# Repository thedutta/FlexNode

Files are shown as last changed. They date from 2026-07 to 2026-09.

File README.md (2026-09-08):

# FlexNode

**A distributed compute node for mobile robots — high-current FOC actuation and sensor fusion, all over CAN-FD.**

> ⚠️ **Work in progress — first article booted 2026-09-06, first motor spin under FOC 2026-09-08.** A v1.0 board powers up, boots from flash, runs the FlexNode firmware, and has driven a GIM 8108-8 open-loop from its own power stage (DRV8353S, all three phase-current channels, bus-voltage sense and FET thermals validated). Still unvalidated: closed-loop FOC and calibration (encoder not yet fitted), the phase-order fix on hardware, CAN enumeration, ToF and aux current sense. Expect breaking changes until the first article is fully proven.

---

## The vision

Building a legged robot today means building three projects: the robot, its electronics, and the firmware to glue them together. FlexNode's goal is to delete the last two.

**Buy FlexNodes + actuators + sensors. Wire power and CAN. Done — no electronics development.**

Each FlexNode is one node per joint: it closes a hard-real-time field-oriented control loop locally (15–30 kHz), reads its own IMU and time-of-flight sensor, and exposes ports for whatever the joint needs — an external RC servo, an AS5600L joint encoder, a load cell for foot contact, addressable status LEDs. Everything reports and commands over a single daisy-chained CAN-FD pair. One firmware image serves every node; per-node behavior is *configuration*, not code. A host — a Jetson, a laptop, a Raspberry Pi — composes queries per node and gets exactly the telemetry it asks for, at gait-loop rates.

The result: a 21-DoF sensor-fused quadruped's entire electronics stack is ten identical boards (one per BLDC actuator; twelve were ordered for attrition), two wires between them, and a config file. That is sweet for CATBOT (the robot this was built for), and just as sweet for anyone else building anything with motors and sensors on it.

## What it is

FlexNode is a compact 4-layer PCB that fuses a **field-oriented motor controller** and a **sensor-fusion front end** into a single CAN-FD bus node. It began as a fork of the [mjbots **moteus r4.11**](https://github.com/mjbots/moteus) controller — the proven power stage, gate driver, STM32G4 core, FOC firmware, and register protocol are kept intact — and adds the digital sensing and I/O a distributed robot node needs:

- **6-axis IMU** (accel + gyro) for per-node inertial sensing — ten nodes make a distributed IMU array
- **Multizone time-of-flight** ranging (8×8) for proximity / terrain
- **Servo / Aux port** with onboard 5 V current sensing (stall detection)
- **Dedicated I²C port** for AS5600L-class joint encoders or any I²C peripheral
- **SPI pads** with spare GPIOs as chip-selects for SPI peripherals
- **Addressable RGB status** (WS2812)
- Everything on the **moteus CAN-FD register protocol**, extended with a FlexNode register block (`0x080–0x0FF`) — one universal map, per-node-composed queries, host-side fleet autodiscovery

## Core specs (v1.0)

| Domain | Part / value |
|---|---|
| MCU | STM32G473CEU6 / G474CEU6 — Cortex-M4F @170 MHz, 512 KB flash, 128 KB RAM, 5× ADC, 6× op-amp, 3× FDCAN, UFQFPN48 |
| Gate driver | TI DRV8353S (3-phase, SPI-configurable) |
| Power FETs | BSC016N06NS-class — 60 V, 1.6 mΩ, TDSON-8 |
| Motor supply | Up to ~44 V bus (10S LiPo class) |
| Aux rail | LGS5160C sync buck (→ 5 V @ 3 A) + ME6216A33M3G LDO (→ 3.3 V) |
| Rotor feedback | AS5047P magnetic encoder (SPI, on-axis) |
| Comms | CAN-FD 1M/5M via TCAN334G, daisy-chain in/out, leaf-node 120 Ω termination |
| Protocol | moteus register protocol + FlexNode block `0x080–0x0FF` — see [`docs/can-layer.md`](docs/can-layer.md) |
| IMU | ST LSM6DS3TR-C (I²C) |
| ToF | ST VL53L7CX 8×8 multizone (I²C) |
| Status | WS2812B addressable LED |
| Aux I/O | Servo / LED output + 5 V shunt current sense + I²C port + dual CAN ports, all JST-PH |
| Stackup | 4-layer, 1 oz copper (thermally validated for CATBOT's real phase currents; go 2 oz for full moteus current capability) |

## Firmware

Firmware is a fork of moteus, retaining its FOC inner loop, CAN protocol, and flash/bootloader layout. The compatibility layer is **implemented and building**; full deltas in [`docs/firmware.md`](docs/firmware.md):

- **Board identity is hardcoded** to `{family = 0, hw_version = 8}` (r4.11-class). FlexNode repurposes moteus's hardware-detection strap pins (PB11, PC6, PB10), so the runtime autodetection was **deleted outright** — boot never touches the repurposed pins, and `hw_version = 8` selects the correct DRV8353 register tables and r4.11 analog map for free.
- **Pin remaps**: `PC6 → AS5047 CS` (done) · `PB11 → 5 V current sense`, `PC13 → servo/LED`, `PB10 → ToF INT` (with peripheral bring-up).
- **Phase-order fix (implemented)**: the v1.0 copper swaps the A/C motor PWM outputs relative to moteus (PA0 → INHC, PA2 → INHA) while current-sense wiring stays stock — verified pin-by-pin against both schematics. Unfixed, the current loop would regulate the wrong winding. The fix is a **two-line drive-side pin remap** in the hardware table: the PWM CCR mapping follows the pins generically, so the entire control core stays byte-for-byte stock and calibration/`phase_invert` semantics are preserved.
- **Flash budget (measured)**: application image ≈ 408 KiB of the 446 KiB app window → **~36 KiB free** for FlexNode's additions — ample when reusing moteus's non-blocking I²C / SPI-DMA / FDCAN primitives and never blocking the FOC ISR.

## The distributed CAN layer

Designed and specified in [`docs/can-layer.md`](docs/can-layer.md). The short version:

- **Extend, don't invent**: moteus's register protocol already separates a *fixed register map* from *per-node-composed frames* — so every FlexNode shares one universal register layout (`0x080` capabilities bitmask, load cell, AS5600L, IMU, ToF, NeoPixel, servo blocks) while the host queries each node only for what it actually has.
- **One image, N configs**: node identity (CAN id, pin modes, encoder sources, peripheral enables) is persistent config. The whole fleet flashes the same `.elf`.
- **Two-lane cadence**, strictly poll-response: loop-critical data (foot contact, joint angles) rides the per-cycle command+query frame; everything else refreshes on a rotating ~25 Hz slow lane. Promoting a sensor to the fast lane is a host-side change only.
- **Phased host**: bring-up on an mjbots fdcanusb at 250–350 Hz on one chain; scale to 400 Hz–1 kHz by making CATBOT's core board an STM32G4 "spinal cord" driving two chains (the G4 has three FDCAN peripherals).

## Engineering highlights

Choices worth reading the docs for:

- **Buck inductor sized against the silicon, not the app note**: 10 µH at 400 kHz keeps peak inductor current (~3.55 A at full load) under the LGS5160C's 3.7 A high-side current limit — the smaller "typical" value would have current-limited at a third of the rated output.
- **Every BOM line datasheet-verified**: all 37 JLCPCB part numbers resolved and checked against their LCSC datasheets before fab (which caught stale schematic annotations that would otherwise read as fatal design errors).
- **Deleted, not bypassed, hardware autodetect**: less flash, and boot provably never drives the repurposed strap pins.
- **A two-line phase-topology fix**: re-pairing drive and sense windings via the pin table instead of touching control code — zero risk to the FOC core, verified against both netlists first.
- **On-node contact thresholding**: foot contact is computed on the node and read as a single byte in the fast lane — the cheapest possible loop-rate signal, and the seed of local reflexes later.
- **ToF's 84 KB init blob streamed over CAN at boot** instead of consuming flash the MCU doesn't have — the host feeds it through the moteus diagnostic tunnel.
- **Thermal design against real loads**: 1 oz 4-layer copper validated against CATBOT's actual phase-current profile (~2–5 A nominal, ~25 A stall transients) — the actuators thermally limit before the board does.

## About this project

FlexNode and CATBOT are **independently designed and built by [Aditya Dutta](https://thedutta.github.io)**, a third-year undergraduate at **Manipal Institute of Technology, Bengaluru** — no lab budget, no research group, no sponsor: one student, open-source tools, and JLCPCB.

**CATBOT** is the driving target: a 4.9 kg, 21-DoF, super-agile jumping quadruped — high-torque geared hips, lightweight leg motors, a Jetson for perception and locomotion policies, and one FlexNode per actuator fused into a whole-body sensor network. The ambition is deliberately at the edge of what an individual can build: dynamic, sensor-rich legged locomotion of the kind usually gated behind institutional hardware.

The method makes that possible: **stand on proven open source and extend it honestly.** moteus contributes a decade of motor-control engineering; FlexNode contributes the distributed-sensing node architecture, the CATBOT-specific hardware, and the documentation trail — and gives all of it back under the same license. Every schematic, BOM line, firmware delta, and design decision in this repo is public precisely so the next student can start where this project stands instead of where it started.

## Repository layout

FlexNode's files live at the repo root; the upstream **moteus r4** project this forks from is kept intact underneath, in `moteus-r4-parent/`:

```
<repo root>/                     ← FlexNode
├── README.md                    ← you are here
├── .gitattributes               LF pinning for WSL-executed scripts
├── docs/
│   ├── hardware.md              hardware architecture, pin map, power tree
│   ├── firmware.md              firmware port: deltas, phase fix, build/flash
│   ├── can-layer.md             distributed CAN layer: registers, cadence, bus budget
│   └── roadmap.md               status and next steps
├── hardware/
│   ├── FlexNode_schematics.pdf  v1.0 schematic (as ordered)
│   ├── CAD/                     3D model (STEP)
│   ├── manufacturing/           BOM, gerber archive, pick-and-place
│   └── gerbers/                 unpacked gerbers
├── LICENSE                      Apache-2.0 (inherited from moteus)
├── NOTICE                       attribution to moteus / mjbots, trademark note
└── moteus-r4-parent/            ← the moteus r4.11 fork FlexNode builds on
    ├── fw/ hw/ lib/ tools/ …    moteus firmware + build system
    ├── README.md                moteus's own readme
    └── LICENSE                  moteus's original Apache-2.0 (preserved)
```

> **Firmware lives in `moteus-r4-parent/`** and builds from *inside* that directory — its Bazel `WORKSPACE` is the build root. FlexNode's firmware deltas live in `moteus-r4-parent/fw/` (currently concentrated in `moteus_hw.cc`; see [`docs/firmware.md`](docs/firmware.md)).
>
> **Upstream sync:** moteus is deliberately relocated off the repo root so FlexNode is the top-level project, which means `git merge upstream/main` no longer applies cleanly. To pull upstream moteus fixes, `git fetch upstream` and copy/patch the changes into `moteus-r4-parent/` by hand. That manual sync is the accepted trade for owning the root.

## Status

See [`docs/roadmap.md`](docs/roadmap.md) for the live checklist. In short: **first article assembled and booted (2026-09-06) · power tree, flash boot, status LED and IMU validated · first spin 2026-09-08: power stage, phase-current sense, bus sense and FET thermals validated with open-loop drive · CAN layer designed, not yet implemented · encoder fit, closed-loop FOC, phase-order verification and CAN bring-up next.**

## Credits & license

FlexNode derives from the **mjbots moteus r4.11** open-hardware controller by Josh Pieper ([mjbots/moteus](https://github.com/mjbots/moteus), Apache-2.0). The power stage, gate-driver topology, STM32G4 core, FOC firmware, and CAN register protocol follow that project; the sensing suite, distributed-node architecture, CATBOT-specific hardware, and firmware deltas are FlexNode's.

This repository is licensed **Apache-2.0** (`LICENSE` at the root), inherited from moteus and covering FlexNode's additions unless a specific file states otherwise. Attribution and modification notices required by Apache §4 are collected in `NOTICE`; moteus's original license is preserved in `moteus-r4-parent/LICENSE`. Retain the moteus attribution and the upstream link.

"moteus" and "mjbots" are trademarks of mjbots Robotic Systems LLC. FlexNode is **moteus-compatible** (speaks the moteus register protocol and works with `moteus_tool` and fdcanusb) and is not endorsed by or affiliated with mjbots.

Author: **Aditya Dutta** · Manipal Institute of Technology, Bengaluru · Project: **CATBOT**

## Build notes

Working notes for the firmware and bench (what is validated, the bench rules, how to build/flash/debug, and lessons learned) live in [`notes/`](notes/). Read [`notes/README.md`](notes/README.md) first. Bench tooling is in [`tools/bench/`](tools/bench/).

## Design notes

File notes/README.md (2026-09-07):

# FlexNode build notes

Working notes for the FlexNode firmware and bench, kept so that each new session (human or Claude) starts with what the last one learned instead of re-deriving it. These are practitioner notes, not user docs; the polished story lives in [`../docs/`](../docs/).

**Read first, every session:** [`working-together.md`](working-together.md) (how we operate) and [`bringup-log.md`](bringup-log.md) (what is validated vs still gated).

| File | What it holds |
|---|---|
| [`working-together.md`](working-together.md) | Ground rules: commit identity, safety gates on motor work, the `!` prefix for hardware commands, subagent use |
| [`bench-setup.md`](bench-setup.md) | Physical bench: SWD header, the NRST rule, power, ST-Link driver, what "standalone" means |
| [`build-and-flash.md`](build-and-flash.md) | WSL build, image layout, the flash script and its modes, option bytes, flash budget |
| [`debugging-over-swd.md`](debugging-over-swd.md) | Diagnostic toolkit: PC sampling, reading RAM by symbol, what each openocd error actually means |
| [`ws2812-led.md`](ws2812-led.md) | The status LED: behaviour, why the timing is DWT-only, the "colour that never turns off" trap |
| [`firmware-map.md`](firmware-map.md) | Where things live in the fork, how to add a register / an aux I²C device / a config group |
| [`bringup-log.md`](bringup-log.md) | Chronological record of what was validated when, and the remaining hard gates |
| [`hardware-io.md`](hardware-io.md) | What I/O the board actually has, per-node peripheral assignment, and the trades available |
| [`corenode.md`](corenode.md) | Corenode architecture: two-FDCAN split, its own IMU, the IMU-ODR latency finding, pre-schematic snags |
| [`can-layer-design.md`](can-layer-design.md) | Why the CAN layer is shaped the way it is — decisions and the reasoning behind them |
| [`flash-findings.md`](flash-findings.md) | Where the flash actually went, measured. Overturns an earlier assumption |
| [`open-questions.md`](open-questions.md) | Decisions still pending: CAN adapter, encoder, head-gimbal topology, node count |
| [`../reports/`](../reports/) | Dated standing reports for Aditya; first: [`2026-09-07-firmware-flash-optimisation.md`](../reports/2026-09-07-firmware-flash-optimisation.md) — the flash decision document, written to be read once |

Conventions:
- Dates are absolute (YYYY-MM-DD). "Today" rots.
- **Findings carry a date and time stamp** — `YYYY-MM-DD HH:MM TZ` — at the point the finding is
  recorded. Aditya asked for this on 2026-09-07 so that the order things were learned in stays
  recoverable, and it applies to every future finding, not just the ones already here.
- A `> Gotcha:` callout marks something that already cost real time.
- `<!-- self: ... -->` HTML comments are notes-to-self for Claude; invisible on GitHub, visible in the source.
- When a note stops being true, edit it. Don't append contradictions.

Tooling referenced throughout lives in [`../tools/bench/`](../tools/bench/).

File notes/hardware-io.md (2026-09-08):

# Hardware I/O — what the board actually has

What a FlexNode v1.0 can physically be asked to do, and what it cannot. Written because the CAN
channel model made the limits concrete, and because two of them were nearly designed around
incorrectly. Companion to [`../docs/hardware.md`](../docs/hardware.md) (the polished version) and
[`../docs/can-layer.md`](../docs/can-layer.md) §9.

## Off-board I/O inventory

_Recorded 2026-09-07 01:35 IST, from `fw/moteus_controller.cc:401-500` (family-0 aux tables) and
`fw/moteus_hw.cc` (pin remaps), cross-checked against `docs/hardware.md`._

| Resource | Pins | Peripheral backing | Notes |
|---|---|---|---|
| I²C1 | PB8 / PB9 | `I2C1`, `USART3` alt | aux2. Onboard LSM6DS3TR-C (0x6A) + VL53L7CX (DNP) + J2 external port. 2 kΩ pull-ups |
| Servo / LED out | PC13 | **TIM1_CH1N (AF4), TIM8_CH4N (AF6)** | aux1 pin 0. No *aux-table* timer, but the silicon has two |
| SPI2 pads | PB13 / PB14 / PB15 | `SPI2`, ADC | aux1 pins 1–3. Also ADC-capable |
| 5 V rail sense | PB11 | ADC | 50 mΩ high-side shunt, ~32 mA/LSB |
| ToF INT | PB10 | EXTI | |
| Debug / GPIO | PC14 / PC15 | nothing | aux2 pins 2–3 |
| WS2812 | PF0 | bit-banged, DWT-timed | status LED, see [`ws2812-led.md`](ws2812-led.md) |
| Rotor encoder | PC6 (CS) | **SPI2? see gotcha** | AS5047P, **not yet soldered** |

> Gotcha, 2026-09-07 02:40 IST: **"PC13 has no timer" is false as a hardware claim** — I recorded
> it that way earlier. It has no timer *in the moteus aux table*. The G474 maps `PC_13` to
> **TIM1_CH1N (AF4)** and **TIM8_CH4N (AF6)** (`TARGET_STM32G474xE/.../PeripheralPins.c`), so a
> **hardware-timed servo pulse via TIM8_CH4N** is available — and TIM8_CH4N is the right choice
> over TIM1_CH1N because TIM1 is wanted for the SimpleFOC Mini below. The RTC-domain drive
> caveats (weak ~3 mA, slow slew) still stand. Lesson: an absent entry in a vendor table is not an
> absent capability in the silicon.

> ⚠️ Gotcha, 2026-09-08: **the AS5047 may be on SPI2 = PB13/PB14/PB15, not SPI1.** This file
> previously recorded SPI1. For family 0 the onboard AS5047 appears to ride **SPI2**
> (`moteus_controller.cc:409-411,518-520`, `aux_mbed.h:604-605`, upstream `encoders.md:188-190`).
> If true, the "SPI expansion pads" **are the rotor-encoder bus**, and the plan to drive a
> SimpleFOC Mini from TIM1_CH1N/2N/3N on those same pins collides with the one peripheral the axis
> cannot lose. **This is now the deciding question for the Mini, and it is a netlist check on the
> real board, not a code read.** Trace PB13/14/15 and the AS5047 before any `bldc_ext` work.

> Gotcha, 2026-09-07 01:35 IST: **the aux hardware tables are still stock moteus r4 pinouts.**
> `GetAux1HardwareConfig()` / `GetAux2HardwareConfig()` in `fw/moteus_controller.cc` were never
> updated for FlexNode, because FlexNode reports `hw_family = 0` and inherits the r4 tables.
> Aux2 happens to be right (PB8/PB9 I²C is genuinely where the IMU is, and it is verified working).
> Aux1 is **not** verified against the FlexNode PCB — PC13 matches, PB13/14/15 are plausible given
> the "SPI expansion pads" in `docs/hardware.md`, but nobody has traced them on a real board.
> Do that before designing anything that depends on aux1.

## Per-node peripheral assignment

_From Aditya, 2026-09-07 01:35 IST. This is design intent, not something read off the board._

Every node is "one actuator plus what that joint needs to know about itself", and the assignment
was **spaced deliberately from the beginning** so no node is overloaded:

- **One servo per node, never two.** The 7 DS3235/DS3230 servos hang off 7 *different* FlexNodes.
- **Shoulder nodes (2× GIM 8108-8) each carry a SimpleFOC Mini as well as their main axis.** One of
  the two also has a DS3235; the other has spare capacity for load cell / RGB / whatever.
- Nodes are meant to have a **local id/name**, not just a numeric CAN id — see
  [`can-layer-design.md`](can-layer-design.md).

> Gotcha, 2026-09-07 01:35 IST: I initially recommended a **PCA9685 I²C PWM expander** to solve
> "seven servos, one pulse pin". **That recommendation was wrong and is withdrawn** — it solved a
> problem that does not exist, because the servos were never going to share a node. One pulse on
> PC13 is sufficient *per node* — and per the correction above it can even be hardware-timed via
> TIM8_CH4N. The lesson is to ask how the mechanical layout distributes load before optimising a
> per-node resource.

## The trades available

Aditya, 2026-09-07 01:35 IST: *"pc13 is definitely not alone, the i2c pins can be repurposed as
gpio if the lsm6dtr is not used — didnt think that one out i think desoldering it works though.
i2c fallback gpio expansion is always an option."*

So the per-node resource picture is a **trade**, not a fixed budget:

| Keep | Give up | Gain |
|---|---|---|
| IMU + ToF + I²C encoders + I²C ADC on PB8/PB9 | PB8/PB9 as GPIO | the whole I²C peripheral ecosystem on 2 wires |
| PB8/PB9 as plain GPIO (desolder the LSM6DS3TR-C) | IMU, ToF, all I²C peripherals | 2 free GPIOs |
| I²C **plus** an expander (PCA9685 / MCP23017) | nothing | many PWM or GPIO channels on the existing 2 wires |

The expander option is the interesting one and stays on the table for *future* nodes that need
more channels than v1.0 breaks out — it just isn't needed for the servos.

Practical consequence for the channel model: a node's populated channel list is genuinely
per-node, and two nodes with identical silicon can differ by a desoldering operation. That is
exactly why capabilities are discovered at runtime (register 0x080 / channel `type`) rather than
assumed from a part number.

## What is still genuinely blocked

**The SimpleFOC Mini.** A Mini (DRV8313-class) needs 3 PWM + enable. PC13 cannot supply that, and
the shoulder nodes need it *simultaneously with* their own GIM 8108-8 on the main axis — so this
is not an either/or with the onboard FOC, it is an addition to it.

Candidate path: **PB13/PB14/PB15 → TIM1_CH1N (AF6) / CH2N (AF6) / CH3N (AF4)**, confirmed in
`TARGET_STM32G474xE/.../PeripheralPins.c`. Three hardware PWM channels from one timer is exactly
what a Mini wants.

> Gotcha, 2026-09-07 02:40 IST: **motor PWM is on TIM5, not TIM2.** I recorded TIM2 earlier and it
> was wrong. `moteus_hw.h` defaults `pwm1/2/3 = PA_0_ALT0 / PA_1_ALT0 / PA_2_ALT0`; on the G474
> map `PA_x_ALT0` is **TIM5_CHx (AF2)** — plain `PA_x` would have been TIM2 (AF1). TIM5 is also the
> CAN bootloader's time base. The conclusion (TIM1 is free) survives; the reasoning did not.

**Timer allocation, audited 2026-09-07 02:40 IST.** Claimed: **TIM5** (motor PWM + bootloader),
**TIM15** (mbed `us_ticker` + `MillisecondTimer`), **LPTIM1** (ADC trigger, `bldc_servo.cc:685`);
TIM2/TIM3 only if aux1 hardware quadrature is configured; TIM4 only in non-FlexNode families.
**Free: TIM1, TIM8, TIM16, TIM17, TIM20.**

Four constraints on the TIM1 path, none fatal, all easy to trip over:
- **`PB_14` is in FlexNode's aux1 pin table** (slot 1, ADC ch5) — must be `kNC` or aux and the Mini
  fight over it.
- **CHxN-only drive needs `CCxNE`/`CCxNP` + `MOE`** — complementary outputs are not enabled by the
  ordinary channel-enable path.
- **TIM1 BRK shares a vector with TIM15** (`TIM1_BRK_TIM15_IRQn`), which mbed uses. Don't enable
  TIM1 break interrupts.
- **A shoulder node with both a Mini and a DS3235 cannot put the servo on TIM1_CH1N/PC13** — same
  channel as PB13. Use **TIM8_CH4N** for the servo.

Costs:
- the SPI expansion pads (SPI peripherals and an external BLDC become mutually exclusive);
- a **second commutation path in firmware** — open-loop or lightly closed against an I²C
  AS5600/MT6701, not a second FOC stack. Budgeted **~10–13 kB**, which now fits easily. **Write it
  separate; share nothing with `bldc_servo`.**
- **CPU**, on a core already running a 30 kHz FOC ISR. **Headroom unmeasured** — no ISR cycle
  instrumentation exists. Only metric: `system_info.idle_rate` (`system_info.cc:75`), readable over
  SWD as a delta of `moteus::SystemInfo::idle_count`.

> Gotcha, 2026-09-07 02:40 IST: **the CORDIC is a single shared peripheral**, used inside the FOC
> ISR with a write→read sequence. A main-loop user gets pre-empted mid-transaction and reads
> someone else's result. A Mini commutation path must use **software sin/cos or a LUT — never the
> shared CORDIC.** Failure mode would be rare unreproducible torque glitches on *both* axes, which
> is close to the worst thing to debug on this machine.

Firmware-side availability confirmed 2026-09-07 02:40 IST; **pad breakout on the real board is not** — trace it. Three options and their trade-offs are written up
in [`../docs/can-layer.md`](../docs/can-layer.md) §9.2. Nothing should be committed to a v1.1
board revision until TIM1 availability and the PB13/14/15 breakout are confirmed on real hardware.

## Possible bench unblock: moteus_tool over serial, no CAN adapter

_Found 2026-09-07 03:05 IST while auditing removable drivers — the driver that looked most cuttable
turned out to be the most useful thing on the bench._

moteus has a **`kSerial` aux UART mode** (`aux_common.h:104`, "fdcanusb ASCII protocol for serial
control") backed by a `UartFdcanusbMicroServer` (`aux_port.h:443,1404`). It speaks the **full
multiplex register protocol over a plain 3.3 V UART** — same protocol as CAN, same registers, same
`moteus_tool`.

On family 0, **USART3 is on PB_8 / PB_9** (`fw/moteus_controller.cc:462-463`) — exactly the pins
broken out on FlexNode's **J2 I2C port**. So a ~$2 USB-TTL adapter on J2 plausibly gives
`moteus_tool` access **without an fdcanusb**.

Unblocks most of what is gated on "no CAN adapter":
- enumerate the node, read 0x080 (capabilities) and 0x0FF (block version)
- read bus_V vs a DMM — **the R30 rescale has never been verified**
- write 0x0B1 = 255 and watch the LED go red (pixel regs are on PF0, independent of this bus)
- exercise `conf set` / `conf write` and the persistent-config page for the first time

> Gotcha: **the IMU and ToF live on that same bus.** Serial mode and I2C are mutually exclusive —
> while the port is a UART the IMU is unavailable. Fine for the list above; don't expect both.

Check before relying on it:
- **PB8 is also BOOT0.** nSWBOOT0 is already cleared so boot-from-flash is safe, but the pin is
  doing triple duty (BOOT0 / I2C / UART) — verify idle levels.
- **The site's connector list mentions a TX/RX header that docs/hardware.md does not.** If one
  exists in copper, find which pins — family-0 aux1 has no USART, so it would be PB8/PB9 anyway.
  Netlist question for Aditya.

> Gotcha: `kSerial` / `UartFdcanusbMicroServer` (5,917 B) was on the flash cut list. **Do not cut
> it** — it may be the only way to talk to a FlexNode until a CAN adapter exists. A neat
> illustration of why "unused driver" is a claim to verify, not assume.

## I²C bus loading

Everything shares one bus: IMU + ToF + every I²C encoder + a load-cell ADC + any expander. At
400 kHz an AS5600 angle read is ~150 µs and an IMU burst ~300 µs, so a node polling both at 1 kHz
spends ~45 % of the bus. Two cheap mitigations:

- The 2 kΩ pull-ups are **already sized for Fast-mode Plus (1 MHz)**, which cuts all of the above
  by ~2.5×. Verify with a scope on the first assembled node.
- Poll rates need not match the control rate. An RC servo's outer loop at 200 Hz is plenty, and
  the IMU is configured for 104 Hz anyway.

Part choice matters here: prefer **NAU7802** (I²C, 24-bit) for load cells over HX711 (2-wire
bit-bang, needs two GPIOs) and ADS1220 (SPI, contends with the pads above).

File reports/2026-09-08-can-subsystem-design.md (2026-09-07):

# CATBOT CAN subsystem — design

_2026-09-08. Supersedes the fleet assumptions in [`docs/can-layer.md`](../docs/can-layer.md) (13 nodes, Jetson-or-brainstem master) with Aditya's corrected inputs of 2026-09-08: **10 FlexNodes, every one with its own BLDC axis, varying effectors, one corenode as bus master, Jetson behind the corenode, ~45 cm bus.** Builds on [`reports/2026-09-07-can-layer.md`](2026-09-07-can-layer.md). Where this document contradicts `docs/can-layer.md`, §12 lists the spec change._

> **Nothing here has been tested. There is no CAN adapter on the bench.** Every byte count is derived from the moteus source in this repo (file:line cited); every microsecond is arithmetic from the CAN FD frame format and the TCAN334G datasheet; every "recommended" value is untested. The three quantities that most need measuring before this is trusted are marked **[measure]**.

---

## 0. Bitrate is not loop rate — read this first

Aditya: *"I do not understand what Hz has to do with anything, I thought CAN-FD maxes out at 5 Mbps, so Hz is the clock speed of CAN?"*

There are two different numbers, and they live at different layers.

**Bitrate** is a property of the wire. CAN FD sends each frame in two phases: the *arbitration phase* at **1 Mbit/s** (one bit every 1 µs — slow, because every node must see every bit before the next starts so that two nodes starting together can resolve who wins), and the *data phase* at **5 Mbit/s** (one bit every 200 ns — fast, because by then exactly one node is transmitting). Both numbers are fixed by the transceiver (TCAN334G is a 5 Mbit part), the controller configuration (`fw/moteus.cc:213-214`: `slow_bitrate = 1000000; fast_bitrate = 5000000`) and the ISO standard. They say how long *one frame* takes on the wire. They say nothing about how often you send one.

**Loop rate in Hz** is a schedule the master chooses. One "cycle" means: the corenode sends every node its command and gets every node's reply. The loop rate is how many such cycles happen per second. It is bounded by the bitrate — you cannot complete a cycle faster than the sum of all its frames — but it is not the same thing, any more than a road's speed limit is the same as how many buses a day you run on it.

The derivation, end to end, with real numbers (details in §3 and §5):

| Step | Quantity | Value |
|---|---|---|
| 1 | Time for one 16-byte command frame on the wire (48 arbitration-rate bits at 1 Mbit + 161 data-rate bits at 5 Mbit) | **80 µs** |
| 2 | Time for the node's 12-byte reply | **74 µs** |
| 3 | Per-node round trip (command + reply), plain actuator node | **154 µs** |
| 4 | Ten nodes, using the actual mix in §5 (two heavy, six medium, two plain) | **1,704 µs** |
| 5 | Plus one slow-lane request+reply pair per cycle (§5.3) | **+246 µs → 1,950 µs per cycle** |
| 6 | Maximum loop rate if the bus were 100 % busy: 1 / 1.95 ms | **513 Hz** |
| 7 | Keep the bus ≤ 65–70 % busy (retransmissions, error frames, node turnaround jitter, bit stuffing): 513 × 0.65…0.70 | **330–360 Hz usable** |

So: **5 Mbit/s is the wire; ~350 Hz is the schedule; the bus is then about two-thirds occupied.** The coordinator's rough figures (≈190 µs per node, ≈1.9 ms per cycle, ≈515 Hz ceiling, 300–400 Hz usable) check out: per node it is 154–194 µs on the fast lane plus a 25 µs share of the slow lane, the cycle is 1.95 ms, the ceiling 513 Hz, and the usable band 300–385 Hz depending on how much margin you keep.

Two rates that are *not* the loop rate, for orientation: the FOC current loop inside each FlexNode runs at 30 kHz and never touches the bus; the Jetson's policy runs at whatever rate it runs and the corenode interpolates between its outputs at bus rate.

---

## 1. Topology

```
 Jetson Orin Nano Super ──(USB / UART / SPI — undecided, §11)── corenode (STM32G4, FDCAN1)
                                                                    │ J3
                                                          FlexNode 1 ── 2 ── 3 ── … ── 10
                                                          (120 Ω)                    (120 Ω)
```

- **One master.** The corenode owns every frame on the bus. FlexNodes transmit only in reply to a frame addressed to them (the single exception, if it is ever built, is §9).
- **10 nodes, ids 1–10**, daisy-chained J3-in/J4-out per [`docs/hardware.md`](../docs/hardware.md), terminated at the corenode end and at node 10 only.
- **Jetson behind the corenode.** The Jetson never appears on the CAN bus. The corenode is the only node that can be a G1 beacon source (§9) and the only thing that can enumerate the fleet.
- **Growth path:** a second chain on the corenode's FDCAN2 (the STM32G4 has three FDCAN instances). Not needed at 10 nodes (§6).

The corenode must therefore have FDCAN. **An STM32G0 cannot be the corenode** — it has no FDCAN peripheral. This settles the G0/G4 question raised in `open-questions.md` §8 as far as the bus master goes; whether a separate G0 exists for the zero-watt acoustic-wake duty is a power-architecture question, not a bus one.

---

## 2. Physical layer

### 2.1 Propagation over 45 cm: not a constraint

Signal velocity in twisted pair is ≈ 0.2 m/ns (≈ 5 ns/m). End to end over 45 cm: **≈ 2.3 ns one way, ≈ 4.5 ns round trip.**

- Against the **1 µs arbitration bit**: the CAN arbitration rule is that a dominant bit from the far end plus the transceiver loop delay must arrive before the local sample point. Round trip is 2 × (2.3 ns + 135 ns loop) ≈ 275 ns against a sample point at 671–800 ns (§2.4). **Margin ≈ 400–500 ns.** Length is 0.5 % of the budget; the transceiver is the rest.
- Against the **200 ns data bit**: only one node transmits, so propagation does not limit anything except the transmitter checking its own bit (§2.5).
- **Where length would start to matter.** Arbitration at 1 Mbit fails when 2 × (5 ns/m × L + 135 ns) exceeds roughly 600 ns, i.e. **L ≈ 30–40 m** — the textbook "40 m at 1 Mbit". At 5 Mbit the limit is not propagation but ringing: the TCAN334G differential edge is ≈ 17 ns (datasheet t_r), and a line is electrically "lumped" — reflections are invisible — while its round trip is well under the edge time. At 5 ns/m that is roughly **< 1 m total**, with stubs under ≈ 30 cm. CATBOT's 45 cm bus is comfortably inside. Past ~1–2 m of total wire, or stubs past ~30 cm, the data phase would start to need CiA 601-style stub discipline. *(Rule-of-thumb figures; the ISO/CiA guidance is not in this repo.)*

### 2.2 Star vs daisy-chain at 45 cm

**Would a star work?** Electrically, at this length, yes. A hub with ten ≤ 20 cm stubs has stub round trips of ≈ 2 ns, an order of magnitude under the 17 ns edge, so each stub's reflection is over before the driver has finished the edge. Total capacitive load — ten transceivers at ~20 pF plus ~1.5 m of wire at ~50 pF/m — is ≈ 300 pF, and the TCAN334G is characterised at 100 pF (60 Ω) and 200 pF (120 Ω). The star would sit somewhere between those two datasheet columns: functional, with the "highly loaded" loop-delay figure (180 ns max) becoming the relevant one — which matters for §2.5.

**Daisy-chain is still the right call, for reasons that are not convention:**

1. **The hardware already does it.** J3-in/J4-out is on every board; a star needs a hub board with ten connectors and twenty crimps that does not exist.
2. **Termination is unambiguous.** Two physical ends, two 120 Ω bridges. A star has no "ends" — you terminate the two longest branches and hope, which is exactly the kind of thing that works on the bench and fails at 40 °C.
3. **Wire mass and routing.** A chain along a limb is one pair going out and one coming back at each joint; a star is ten pairs converging on the torso.
4. **Lower total capacitance**, keeping the transceiver in its 100 pF column.

The one real cost of a chain: a break in the pair at joint *k* kills nodes *k+1…10* and leaves nodes *1…k* single-terminated. At 45 cm single-termination still works (§2.3), so the upstream half degrades rather than dies. That is the fault-containment argument for two chains later.

### 2.3 Termination: what actually goes wrong

Nominal: 120 Ω at each physical end, 60 Ω in parallel as seen by any driver.

- **A middle node also terminated (three resistors, 40 Ω).** The driver must source ~50 % more current to reach the same differential voltage. The TCAN334G guarantees ≥ 1.5 V dominant differential into 60 Ω; into 40 Ω the amplitude drops toward the 0.9 V receiver threshold and the margin against noise and ground offset shrinks. It usually still "works" on a short quiet bench bus and fails first in the field. Every node terminated (12 Ω) and the driver cannot reach dominant at all — the bus is dead.
- **Only one end terminated (120 Ω).** Dominant amplitude is fine (higher, in fact). The problem is the *recessive* edge: nothing drives recessive; the terminators pull the pair back together through the bus capacitance. Doubling R doubles that time constant. The datasheet's "highly loaded" column (120 Ω, 200 pF) is exactly this case, and it lists loop delay up to **180 ns** and 5 Mbit received-bit symmetry down to 120 ns — against a 200 ns bit. At 1 Mbit you will not notice. At 5 Mbit, bit-symmetry and the transmitter's own loopback check (§2.5) start failing intermittently. Diagnosable: it works with `bitrate_switch` off and fails with it on.
- **Neither end.** Reflections from open ends; at 45 cm they settle in nanoseconds, so it may even work — right up to the first cable that is a bit longer. Do not.

### 2.4 Bit timing on the STM32G4 FDCAN

FDCAN kernel clock is PCLK1 = **85 MHz** (the firmware's own comment: `tdc_offset = 13; // 13 / 85MHz ~= 152ns`, `fw/moteus.cc:226`). `MakeTime()` (`fw/fdcan.cc:44-72`) picks prescaler 1 and splits the remaining time quanta ≈ 3 : 1 between seg1 and seg2. What the FlexNode firmware therefore programs today:

| Phase | tq per bit | Prescaler | Seg1 | Seg2 | SJW | Sample point |
|---|---|---|---|---|---|---|
| Nominal, 1 Mbit | 85 | 1 | 56 | 28 | 16 | (1+56)/85 = **67 %** |
| Data, 5 Mbit | 17 | 1 | 11 | 5 | 5 | (1+11)/17 = **71 %** |

Both sample points are earlier than usual practice (CiA recommends ≈ 80 % nominal, 75–80 % data; the STM32 examples use 80 %/75 %). Earlier sampling is more tolerant of ringing and less tolerant of propagation and loop delay. On a 45 cm bus ringing is a non-issue and loop delay is the whole budget, so **later is better here**:

| Phase | Recommend | Sample point | Why |
|---|---|---|---|
| Nominal | prescaler 1, seg1 = 67, seg2 = 17, SJW = 17 | 68/85 = **80 %** | Standard; maximises the arbitration loop-delay budget. |
| Data | prescaler 1, seg1 = 12, seg2 = 4, SJW = 4 | 13/17 = **76.5 %** | Pushes the loopback check 12 ns later (§2.5); SJW 4 tq (47 ns) still covers oscillator tolerance between HSI-clocked nodes. |

Both are within the G4 limits `MakeTime` enforces (255/127 nominal, 31/15 data). The mechanism to apply them without touching `MakeTime` already exists — `ApplyRateOverride` (`fw/fdcan.cc:74-89`) — but the `Rate` override struct is not currently exposed as `can.*` config; that is a small firmware addition. **Every node and the corenode must use identical settings.** Clock source caveat: FlexNode has no HSE crystal (`docs/hardware.md`), so the 85 MHz derives from HSI16 at ±1 % over temperature; SJW ≥ 4 tq in the data phase is what absorbs that. **[measure]** with an adapter: error counters at 5 Mbit over a warm-up.

### 2.5 Transceiver reality check: TDC

At 5 Mbit the transmitting controller compares each bit it sends against what it reads back through its own transceiver, at the data sample point. If the transceiver's loop delay exceeds the sample-point position, it reads the *previous* bit and raises a bit error. Transmitter Delay Compensation (TDC) moves that check later by a measured/configured offset.

| | Value | Source |
|---|---|---|
| Data sample point, firmware today | 12 tq / 85 MHz = **141 ns** after bit start | §2.4 |
| TCAN334G loop delay, 60 Ω / 100 pF | 100 ns typ, **135 ns max** | datasheet SLLSEQ7F §5.6 `tPROP(LOOP)` |
| TCAN334G loop delay, 120 Ω / 200 pF | 120 ns typ, **180 ns max** | same |
| MCU pin + controller internal delays | ~10–20 ns | estimate |
| TDC in FlexNode firmware | **disabled** for family 0 | `fw/moteus.cc:224`: `delay_compensation = g_measured_hw_family != 0` |

The moteus comment says family 0 "uses a TCAN334GDCNT, which has a very low loop delay". The datasheet says the margin at the firmware's sample point is **141 − 135 = 6 ns** worst case in a well-terminated bus, and **negative** in a heavily loaded or single-terminated one. Thousands of moteus r4.x boards run 5 Mbit this way, so typical parts clearly clear it — but the design should not rely on typicals.

**Recommendation:** enable TDC for FlexNode — `options.delay_compensation = true`, keep `tdc_offset = 13` (153 ns ≈ seg1 with the §2.4 timing, per ST's guidance of offset ≈ DataTimeSeg1 × prescaler) and `tdc_filter = 2`. It costs nothing, the code path exists and is exercised by other moteus families, and it converts a 6 ns margin into ~150 ns. Two-line change in `fw/moteus.cc`. **[measure]**: with TDC on and off, error counters over 10⁶ frames.

Nothing else about the TCAN334G constrains the design: 5 Mbit is its rated maximum, 45 cm is nothing, and the 100 pF column is where a two-terminator chain of ten sits.

---

## 3. Frame anatomy and cost

### 3.1 Frame time model

CAN FD frame bits, from ISO 11898-1:2015 field lengths:

- **Arbitration rate (1 Mbit):** 11-bit id: SOF 1 + ID 11 + RRS 1 + IDE 1 + FDF 1 + res 1 + BRS 1 = 17 bits up front, plus ACK 1 + ACK-delim 1 + EOF 7 + IFS 3 = 12 bits at the tail → **29 µs**. 29-bit id adds SRR 1 + ID-ext 18 → 36 up front → **48 µs**.
- **Data rate (5 Mbit):** ESI 1 + DLC 4 + 8·N data + CRC field + CRC-delim 1. CRC-17 (N ≤ 16 bytes) with its stuff-count and fixed stuff bits is 27 bits; CRC-21 (N > 16) is 32. So **8N + 33 bits for N ≤ 16, 8N + 38 for N > 16**, at 200 ns each.
- Dynamic bit stuffing in the data adds 0–20 % of the data-phase bits depending on content; it is absorbed in the utilisation margin, not modelled per frame.

**Every command frame is a 29-bit frame**: the host sets bit 15 of the id to request a reply (`lib/python/moteus/transport.py:344`) and the firmware sends any id ≥ 2048 as extended (`fw/fdcan.cc:323-325`). A **reply** has id `(node << 8) | 0`, which is < 2048 for node ids 1–7 (11-bit frame, 19 µs cheaper) and ≥ 2048 for ids 8+. Payloads are rounded up to the next legal DLC — 12, 16, 20, 24, 32, 48, 64 — by `RoundUpDlc` (`fw/fdcan.cc:24-41`).

| Payload (DLC) | 29-bit frame | 11-bit frame |
|---|---|---|
| 8 | 67 µs | 48 µs |
| 12 | 74 µs | 55 µs |
| 16 | 80 µs | 61 µs |
| 20 | 88 µs | 69 µs |
| 24 | 94 µs | 75 µs |
| 32 | 107 µs | 88 µs |
| 48 | 132 µs | 113 µs |
| 64 | 158 µs | 139 µs |

The DLC steps are the whole game for frame design: **33–48 bytes all cost 132 µs; 25–32 all cost 107 µs.** Every frame below is designed to land just under a boundary, and the table says where.

### 3.2 Subframe encoding (stock moteus, `lib/cpp/mjbots/moteus/moteus_multiplex.h`)

Header byte = `0x00` write / `0x10` read / `0x20` reply, `| type<<2` (int8 0, int16 1, int32 2, float 3), `| count` if count ≤ 3, else count 0 and a following count byte (`:646-652`). Then the start register as a varuint (1 byte ≤ `0x7F`, 2 bytes to `0x3FFF`), then the values. Consecutive registers, one subframe.

### 3.3 Arbitration priority — a quirk to know and not rely on

Base id of every corenode command is 0 (bits 28–18 of `0x8000|dest` are zero). Replies from nodes 1–7 are 11-bit frames with base id `node << 8` ≥ 0x100, so **a corenode command always beats them**; replies from nodes 8–10 are extended with base id 0 and a smaller 18-bit extension than the command, so **they beat the corenode**. Consequence: if the corenode streamed ten commands back-to-back, nodes 1–7 could not get a reply in until it paused. The schedule in §5.4 sends with at most two commands outstanding, which sidesteps this entirely. Do not build anything that depends on reply priority.

---

## 4. Node classes and their frames

Aditya: every node has a BLDC axis; some add a servo; some add a servo and a SimpleFOC Mini; some have "other effectors". Four classes cover that; a node's class is whatever its enumerated channel list says (`docs/can-layer.md` §8), not a build-time choice.

Design rules applied to all of them (each a spec change, §12):

- **Fast pair.** Each channel's per-cycle command is `cmd_a, cmd_b` (2 × int16 at `+4`) and its per-cycle readback is `meas_a, meas_b` (2 × int16 at `+7`). `cmd_c` (effort limit) and `meas_c/d` go on the slow lane. Two registers keep the count in the header's low bits — no count byte — so a channel command is 7 B and a readback request 3 B / reply 7 B.
- **Axis fast query is `0x000–0x003` only.** Voltage, temperature and fault (`0x00D–0x00F`) move to the slow lane. Mode (`0x000`) is read every cycle and equals 1 on fault, so fault *detection* latency is unchanged; only the fault *code* waits ≤ 29 ms for the slow lane. This saves 2 B in every command and 5 B in every reply — which is what keeps class C under DLC 32.
- **Mode is written every cycle** (`01 00 0A`). It is 3 bytes, it re-arms the axis, and it is what the stock Python library does; not worth optimising away.

### 4.1 Class A — actuator only

**Command → DLC 16** (14 B, 2 B spare)

| Bytes | Subframe | B |
|---|---|---|
| `01 00 0A` | write int8 ×1 @ `0x000` mode = 10 (position) | 3 |
| `07 20 pp pp vv vv tt tt` | write int16 ×3 @ `0x020` position, velocity, ff-torque | 8 |
| `14 04 00` | read int16 ×4 @ `0x000` mode, position, velocity, torque | 3 |

**Reply → DLC 12** (11 B, 1 B spare)

| Bytes | Subframe | B |
|---|---|---|
| `24 04 00` + 8 | mode, position, velocity, torque | 11 |

Round trip: 80 + 74 = **154 µs** (135 µs if the node id is ≤ 7).

### 4.2 Class B — actuator + one servo (slot 1 = `servo_rc`)

**Command → DLC 24** (21 B, 3 B spare)

| Bytes | Subframe | B |
|---|---|---|
| (class A command) | | 14 |
| `06 94 04 aa aa ss ss` | write int16 ×2 @ `0x214` servo angle, slew | 7 |

No servo readback on the fast lane: a DS3235 has no feedback unless an `enc_i2c` is bound, and its 5 V current (stall detection) is a 35 Hz question. **Reply → DLC 12**, as class A. Round trip **168 µs** (149 µs, id ≤ 7).

Designed under the boundary: 14 + 7 = 21 ≤ 24. Adding a 3-register servo command (with `cmd_c`) would make 23 — still 24. Adding the 3-byte servo readback request would make 24 — still 24, but the reply would go 11 + 7 = 18 → DLC 20 (+14 µs). If a servo *does* have a bound encoder and its angle matters at gait rate, that is the price.

### 4.3 Class C — actuator + servo + SimpleFOC Mini (slot 1 `servo_rc`, slot 2 `bldc_ext`)

**Command → DLC 32** (31 B, 1 B spare — this is the tightest frame in the fleet)

| Bytes | Subframe | B |
|---|---|---|
| (class A command) | | 14 |
| `06 94 04 aa aa ss ss` | servo angle, slew @ `0x214` | 7 |
| `06 A4 04 pp pp vv vv` | write int16 ×2 @ `0x224` Mini position, velocity | 7 |
| `16 A7 04` | read int16 ×2 @ `0x227` Mini position, velocity | 3 |

**Reply → DLC 20** (18 B)

| Bytes | Subframe | B |
|---|---|---|
| `24 04 00` + 8 | axis | 11 |
| `26 A7 04` + 4 | Mini position, velocity | 7 |

Round trip 107 + 88 = **195 µs** (176 µs, id ≤ 7).

This is where the two design rules pay: with the spec's original 3-register commands and 4-register readbacks and `0x00D–0x00F` on the fast lane, this command would be 47 B → DLC 48 (132 µs) and the reply 27 B → DLC 32 (107 µs): **239 µs**, 44 µs more per cycle per shoulder. One more byte in the command as designed and it also jumps to 48 — so **class C has no room for a third effector on the fast lane.** A third effector goes on the slow lane or costs 26 µs.

### 4.4 Class D — actuator + one fast input (foot load cell, or output-side encoder)

Command = class A + `16 97 04` (3 B) = 17 → **DLC 20**. Reply = 11 + 7 = 18 → **DLC 20**. Round trip **176 µs** (157 µs, id ≤ 7). Which nodes, if any, carry a foot load cell is not stated anywhere; class D is here so the budget can absorb it.

---

## 5. The schedule

### 5.1 What rotates and what does not

Aditya asked for round-robin keyed off node id so nothing starves. The answer is that **the fast lane is not a rotation at all: every node is served every cycle, in id order 1→10.** Starvation is impossible by construction. What rotates is the **slow lane**: on cycle *c*, node `(c mod 10) + 1` additionally receives a slow-lane request. Keying it off the id means the schedule is a counter and a modulo, which is exactly right for a purpose-built fleet.

At 350 Hz that is **35 slow-lane visits per second per node**. Whether that is a 35 Hz refresh of *everything* depends on whether a node's slow block fits one 64-byte reply (§5.3).

### 5.2 Fast lane composition, per cycle

Assumed fleet — the counts are Aditya's qualitative statement turned into numbers and are **assumed, not stated**: 2 class C (the two shoulder nodes: GIM 8108-8 + Mini, one with the DS3235), 6 class B (six more servos, one per node, on six actuator nodes — that uses all seven published servos), 2 class A. If "other effectors" add fast channels, they move a node to class D at +22 µs each.

| Class | Count | Cmd / reply DLC | Round trip (id ≥ 8 / id ≤ 7) | Subtotal (all extended) |
|---|---|---|---|---|
| C | 2 | 32 / 20 | 195 / 176 µs | 390 µs |
| B | 6 | 24 / 12 | 168 / 149 µs | 1,008 µs |
| A | 2 | 16 / 12 | 154 / 135 µs | 308 µs |
| **Fast lane** | 10 | | | **1,706 µs** |

Give ids 1–7 to the seven busiest nodes and the fast lane drops to ≈ 1,573 µs. The budget below uses the conservative all-extended figure.

### 5.3 Slow lane

One request+reply pair per cycle, to the rotating node. Content, in one 64-byte reply where it fits:

| Subframe (request) | Reply bytes | What |
|---|---|---|
| `13 0D` | 5 | voltage, temperature, fault |
| `14 08 80 01` (int16 ×8 @ `0x080`) | 20 | caps, status, rail current, profile, build hash, channel count, fleet role, host-loss state |
| `14 06 98 01` (int16 ×6 @ `0x098`) | 16 | IMU accel + gyro (v1 alias) |
| per channel: `16 92 04` (+2..+3) and `17 99 04` (+9..+B) | 8 + 10 | status, mode; `meas_c`, `meas_d`, nonce |

Class A/B/D: 5 + 20 + 16 + 18 = **59 B → DLC 64** ✓ (35 Hz for the whole block). Class C: two channels = 77 B — does not fit. **For class C the slow lane alternates**: even visits carry health + IMU, odd visits carry both channel blocks; each half refreshes at **17.5 Hz**. That is still above the 25 Hz the spec called "ample" for IMU bias tracking only on A/B nodes; for the two shoulders it is below it. If the shoulder IMUs turn out to feed state estimation, promote their IMU read to the fast lane on those two nodes (+4 B request, +16 B reply → command DLC 48 on a class C node: +26 µs each; budgeted in §6 as "next thing that breaks").

Slow request ≈ 20 B → DLC 20 (88 µs); reply DLC 64 (158 µs). **Slow pair = 246 µs per cycle.** Slow-lane *writes* — `cmd_c` effort limits, `0x023–0x029` gains and limits, servo re-arm — ride in the same request frame; they cost reply bytes only if they ask for a reply (they should not).

### 5.4 Cycle timeline at 350 Hz (period 2,857 µs)

The corenode keeps **at most two commands in flight** (send command *k+1* as soon as command *k* has left the TX FIFO, but never command *k+2* until reply *k* has arrived or a 300 µs per-node timeout has expired). This hides node turnaround behind the next command's transmission, guarantees the bus is free for a reply after every second command regardless of the priority quirk in §3.3, and bounds the damage from a dead node to one timeout per cycle.

```
 t (µs)   bus
    0     ┌─ cmd 1 (C, 107) ─┐┌─ cmd 2 (C, 107) ─┐┌ reply 1 (88) ┐┌─ cmd 3 (B, 94) ─┐┌ reply 2 (88)┐
  ~480    ┌─ cmd 4 (B) ─┐┌ reply 3 (74) ┐┌─ cmd 5 (B) ─┐┌ reply 4 ┐┌─ cmd 6 (B) ─┐┌ reply 5 ┐ …
 ~1540    … ┌─ cmd 10 (A, 80) ─┐┌ reply 9 ┐┌ reply 10 (74) ┐
 ~1710    ┌─ slow req → node (c mod 10)+1 (88) ─┐┌──────── slow reply, DLC 64 (158) ────────┐
 ~1950    ┌ FaF pixel (67) ┐┌ FaF servo-arm (67) ┐  … up to a cap of 3 frames / 250 µs
 ~2200    ·········· idle slack ≈ 650 µs (retransmits, error frames, stuffing, turnaround jitter) ··········
 2857     next cycle
```

Where each thing lands:

- **Fast lane, 0 → ~1,710 µs.** Commands in id order; replies interleave. Reply *k* arrives after node *k*'s turnaround, which is main-loop latency (`fw/moteus.cc:348-353` polls CAN RX from the `for(;;)` loop) — **[measure]**, unmeasured, probably tens of µs, hidden by the two-in-flight rule as long as it is under one frame time.
- **Slow lane, ~1,710 → ~1,960 µs.** One pair.
- **Fire-and-forget, ~1,960 → ~2,200 µs.** Pixel colour, tare, servo re-arm, named-posture broadcast: drained from a queue with a per-cycle cap (3 frames or 250 µs) so they can never push the next cycle. Fire-and-forget frames have no reply bit, so they are 11-bit frames (48 + data) — cheap.
- **Slack, ~2,200 → 2,857 µs.** ≈ 23 % of the period. This is where automatic retransmission (`fw/moteus.cc:217`, on) and error frames go without stealing from the next cycle.

The corenode's own FDCAN has, on the G4, a fixed message RAM of **3 TX FIFO elements and 3 + 3 RX FIFO elements** (RM0440; not re-verified in this repo). Ten replies arrive ~75–110 µs apart; the corenode must service RX from an interrupt, not a main loop, or the fourth reply overwrites the first. Note it in the corenode firmware requirements.

### 5.5 Operating points

Cycle cost 1,952 µs (all-extended, assumed mix). Utilisation = cost × rate.

| Loop rate | Period | Bus utilisation | Slack per cycle | Verdict |
|---|---|---|---|---|
| 200 Hz | 5,000 µs | 39 % | 3,048 µs | Bring-up. Room for verbose slow lane, tunnel traffic, debugging. |
| 250 Hz | 4,000 µs | 49 % | 2,048 µs | Comfortable. |
| 300 Hz | 3,333 µs | 59 % | 1,381 µs | **First walking target.** Under the 65 % rule with margin for class-D additions. |
| **350 Hz** | 2,857 µs | **68 %** | 905 µs | **Design operating point.** Just over the 65 % rule; acceptable because the slack is still 4–5 frames wide. |
| 400 Hz | 2,500 µs | 78 % | 548 µs | Ceiling for a single chain. One retransmit storm eats the slack. |
| 450 Hz | 2,222 µs | 88 % | 270 µs | Not viable — slow lane and fire-and-forget starve. |
| 500 Hz | 2,000 µs | 98 % | 48 µs | Not viable. |

With ids 1–7 on the busiest nodes (1,819 µs): 350 Hz → 64 %, 400 Hz → 73 %.

**Recommended: 1 Mbit / 5 Mbit (unchanged), 350 Hz loop, ≈ 68 % utilisation, ≈ 0.9 ms slack.** Bring up at 200 Hz, walk at 300 Hz, tune toward 350 Hz. Nothing in the servo (50–330 Hz devices) or policy path benefits from more, and the FOC loop is local at 30 kHz regardless.

---

## 6. What breaks first, and the upgrade path

In the order it will happen:

1. **A class C node grows one byte.** 31 → 32 is fine; 33 is DLC 48 and +26 µs. Adding a fast IMU read to a shoulder, a third effector, or per-cycle stiffness (§7.2) does it. Two shoulders → +52 µs/cycle → 350 Hz goes from 68 % to 70 %. Survivable once; not twice.
2. **Fast input channels spread.** Each node promoted to class D is +22 µs. Four foot load cells → +88 µs → 71 %.
3. **Node count.** Each added class A node is +154 µs; a class B, +168 µs. At 12 nodes the 350 Hz point is ≈ 80 %. At 13 (the old assumption) it is ≈ 86 % — which is why the old spec's 325 Hz / 65 % line was already optimistic.
4. **Slow-lane refresh** on class C is already at 17.5 Hz per half; a fourth channel on a node pushes it to three-way alternation.
5. **Corenode RX servicing** (§5.4) — a software problem, not a bus one, but it will look like a bus one.

**Upgrade path: second chain on FDCAN2.** Split 5/5 by side (or front/rear). Each chain's cycle is ≈ 0.95 ms; at 350 Hz that is ≈ 33 %, and 600 Hz becomes reachable at ≈ 57 %. Termination: each chain gets its own two ends (corenode end + last node). The corenode runs two identical schedulers offset by half a period so its RX interrupt load is even. The FlexNodes need nothing — `can.prefix` can namespace the two chains if they are ever bridged, but physically separate buses do not need it. This is also the fault-containment split the site already promises ("one bus fault takes down one side"). Not needed at 10 nodes; the design is written so that enabling it is a corenode change only.

---

## 7. Command and telemetry semantics

### 7.1 Who computes what

- **Jetson** runs the policy. Its output should be **per-joint targets** — position, velocity and feed-forward torque for each of the ten axes, plus servo angles and Mini positions — at policy rate. Whether the policy emits joint space directly or foot coordinates that something converts through IK is a Jetson/corenode software decision and is **not stated**; the bus does not care, but the corenode must receive joint-space targets at least as often as it wants to change them, and it interpolates (or holds) between policy updates at bus rate.
- **Corenode** owns the schedule, packs frames from templates (§7.4), unpacks replies into a fleet-state struct, hands the Jetson a consolidated state at whatever rate the Jetson wants, and runs the failure policy (§9) without the Jetson.
- **FlexNode** runs FOC at 30 kHz on the axis, the servo pulse and the Mini commutation locally, and answers what it is asked.

### 7.2 Registers, by lane

| Lane | Direction | Registers | Notes |
|---|---|---|---|
| Fast, every cycle | cmd | `0x000` mode = 10; `0x020` position, `0x021` velocity, `0x022` ff-torque | stock (`fw/moteus_controller.cc:236,270-272`) |
| Fast | cmd | `0x2n4` `cmd_a`, `0x2n5` `cmd_b` per channel | servo: angle, slew · Mini: position, velocity |
| Fast | tel | `0x000–0x003` mode, position, velocity, torque | mode = 1 flags a fault immediately |
| Fast | tel | `0x2n7` `meas_a`, `0x2n8` `meas_b` for Mini (and class-D inputs) | Mini: position, velocity · load cell: force, **contact** · encoder: angle, rate |
| Slow, 35 Hz (17.5 Hz on C) | cmd | `0x023` kp scale, `0x024` kd scale, `0x025` max torque, `0x028` velocity limit, `0x029` accel limit; `0x2n6` `cmd_c` effort limits; `0x2n3` channel mode | stock `0x023–0x02A` (`:273-280`). Written only when changed. |
| Slow | tel | `0x00D–0x00F`; `0x080–0x087`; `0x098–0x09D` IMU; per channel `+2,+3,+9,+A,+B` | see §5.3 |
| Fire-and-forget | cmd | `0x0B0–0x0B4` pixel; tare; servo re-arm; named posture (broadcast `0x7f`) | no reply bit, 11-bit frames |
| Boot only | both | `0x100`, `0x150–0x153`, `0x0FF`, `0x0C0–0x0C3` name, channel `type/caps` | `docs/can-layer.md` §8 |

**Per-cycle stiffness modulation** (`0x023–0x025` every cycle, as some policies want) costs +8 B in every command: class A 22 → DLC 24 (+14 µs), class B 29 → DLC 32 (+13 µs), **class C 39 → DLC 48 (+26 µs)**. Fleet cost ≈ +150 µs/cycle → 350 Hz at 73 %. Affordable on a single chain only if nothing else grows; free on two chains. Decide when the policy exists.

### 7.3 Servo semantics on the wire

`servo_rc` `cmd_a` is the target angle in 0.05° (int16), `cmd_b` the slew limit in 0.5 °/s (resolution table in `docs/can-layer.md` §3.5). The node runs the pulse train and slew limiting; if an `enc_i2c` is bound it closes the outer loop locally. The corenode writes the target every cycle whether or not it changed — that is the servo channel's watchdog refresh (§9). `cmd_c` (5 V current limit for stall cut-off) is slow-lane, once.

### 7.4 Frame templates — how the corenode composes a multi-effector frame

At enumeration the corenode builds, per node, a **byte template**: the fixed subframe headers with the value slots left blank, plus a table of (offset, source-field, scale). Per cycle, packing is a `memcpy` of the template and int16 stores at fixed offsets; no varuint encoding or subframe logic runs in the loop. For the class C node in §4.3 the template is 31 bytes with value slots at offsets 2 (mode), 5–10 (axis), 17–20 (servo), 24–27 (Mini). Unpacking uses the same idea in reverse against the expected reply layout; a reply whose subframe headers do not match the template is a protocol error, logged with the node's name (`0x0C0–0x0C3`) and dropped. Templates change only when the channel list changes — i.e. never at runtime, which is the whole point of "hardware changes need a reflash".

---

## 8. Node identity in this topology

Unchanged from `docs/can-layer.md` §4.1: CAN id (1–10, address), UUID (`0x150–0x153`), name (`0x0C0–0x0C3`). The corenode holds the fleet manifest — ten rows of (id, UUID, name, expected class, expected profile/build hash) — and refuses to start the schedule on any mismatch. Give **ids 1–7 to the two class C and five of the class B nodes** (cheapest replies), 8–10 to the rest. Numbering by id in physical chain order is tidy but not required.

---

## 9. Failure policy with the corenode as the only master

`docs/can-layer.md` §7 was written for a Jetson-or-brainstem master. With the corenode as the sole master three things change: the beacon source is fixed, the fast lane *is* a heartbeat, and the question G2 answers becomes "what if the corenode dies" — a different, rarer, event.

### 9.1 What a FlexNode does when corenode frames stop

**Detection.** Stock: `servo.default_timeout_s` (`fw/bldc_servo_structs.h:612`, default **0.1 s**) is reset by every command frame. At 350 Hz a frame arrives every 2.9 ms, so 100 ms is 35 consecutive missed cycles. **Recommend 30 ms** (≈ 10 cycles): long enough that a retransmit burst or a single dropped reply never trips it, short enough that a fallen corenode is noticed within a stride. Config, not code; can be tuned per node. **[measure]** false-trip rate at 30 ms once the bus is real.

**Axis safe state.** On timeout the axis enters `timeout_mode` (`:622`, default **12 = kZeroVelocity**): a velocity-zero servo loop — it does not hold position, it *damps* motion, with torque capped at `timeout_max_torque_Nm` (`:613`, default **5 Nm**). For a 4.8 kg quadruped that is the right primitive: the robot sags to the ground against damping rather than collapsing or locking. Recommend: hips/shoulders (backdrivable QDD) keep mode 12 with the cap tuned to roughly body-weight support so the sag is slow; knees (14:1 belt, less backdrivable) the same, and evaluate mode 15 (brake) only if the belt turns out to overrun.

**Channel safe state**, per type — new firmware, since channels do not exist yet:

| Type | On timeout | Why |
|---|---|---|
| `servo_rc` | hold last target for `ch.hold_ms` (recommend 200 ms), then `mode = 0` (pulse stops, servo goes limp) | An instantly limp spine/tail drops the torso; a stale target held forever fights the sagging legs. A short hold then release is the compromise. |
| `bldc_ext` (Mini) | `mode = 0` immediately: driver disabled, coast | Open-loop commutation with a stale target is worse than coasting. |
| inputs (`loadcell`, `enc_i2c`, `imu`, `tof`) | keep sampling | Nothing to make safe; data is wanted when the corenode returns. |
| `pixel` | fault pattern on pixel 0 | Human-visible "I have lost my master". |

Recovery is automatic: the next valid command frame re-arms the axis (mode write) and the corenode re-arms channels (`mode = 1`) on its first slow-lane visit.

### 9.2 What the corenode does when a FlexNode stops replying

A node that misses its 300 µs reply window is marked stale for that cycle; three consecutive misses mark it *lost*. The corenode keeps commanding it (the frame costs the same either way and re-arms it the instant it is back), tells the Jetson which limb is degraded, and applies the corenode-level fallback: a **standing posture on the remaining nine** with the affected limb's neighbours commanded to hold. This is the "brainstem still has authority to put the robot into a safe pose" from the site, made concrete. It needs no bus feature at all.

### 9.3 G0 / G1 / G2, reconciled

- **G0 — per-node timeout.** As above. Always on. Now with a 30 ms recommendation and per-channel safe states.
- **G1 — presence beacon.** The corenode is the only possible source. But **the corenode already sends every node a frame every 2.9 ms; the fast lane is the beacon.** A separate 10 Hz broadcast adds nothing for liveness. What survives of G1 is the *fleet-state* half: a fire-and-forget broadcast write to `0x086` (`0x7f` destination, already accepted by every node — `fw/moteus.cc:307,319`) carrying a named posture or a "degrade" flag, so the corenode can put all ten nodes into a posture with one frame when the *Jetson* dies. That is the case G1 should be redefined around: **G1 = corenode-driven degraded mode on Jetson loss**, not node-side beacon tracking. Register `0x087` (host-loss state) stays, driven by the node's own G0 timer.
- **G2 — deputy.** With one master, G2 protects against *corenode* death. **Recommendation: do not build it for CATBOT.** The corenode is a G4 running fixed-rate code with a hardware watchdog and no OS — the "boringly predictable" tier by design; its failure is orders of magnitude rarer than the Jetson's, and when it happens G0 already lands the robot in a damped sag within 30 ms, which is a defensible outcome for a 4.8 kg machine. Against that, G2 adds the only unsolicited transmitter on the bus, a fold sequence executed blind by a node that cannot see its peers, and the failure modes listed in the previous report (a wrong deputy is indistinguishable from the host). The one thing worth taking from G2 is a **corenode hardware watchdog that, on reset, immediately broadcasts a "hold" posture** — which is G1's fleet-state frame, sent by the recovering master. Keep §7's G2 text in the spec as a documented, disabled option for a future multi-master fleet; delete `deputy_rank` from the CATBOT config.

### 9.4 Jetson loss

Not a bus event. The corenode notices its Jetson link is silent (its own watchdog, threshold a Jetson-side question — a few hundred ms), stops interpolating toward stale targets, and drives the fleet to a standing or crouched posture from its own table via the fast lane it is already running. The bus schedule does not change at all. This is the failure that will actually happen, and it is handled entirely above the CAN layer.

---

## 10. Bring-up order for this design

Each step is testable with the adapter and no motor.

1. **Adapter.** Everything below is blind.
2. One node: `moteus_tool --info`, read `0x0FF`, `0x080`, name; measure **node turnaround** (command → reply, scope on CANH). **[measure]** — the number that decides whether §5.4's two-in-flight rule hides it.
3. Error counters at 5 Mbit, TDC off vs on (§2.5); adopt the §2.4 sample points via a `can.*` override.
4. Two nodes, ids 1 and 8: confirm the 11-bit/29-bit reply split and the arbitration behaviour of §3.3 on a scope.
5. Class A schedule at 200 Hz from the adapter host: measure real cycle time against 1.95 ms; fit the stuffing overhead.
6. Channel infrastructure (`docs/can-layer.md` §11 steps 4–7) → class B and C frames; confirm DLC 24 / 32 on the wire.
7. G0 at 30 ms: pull the adapter mid-schedule, scope the time to mode 12.
8. Corenode firmware: templates, two-in-flight, RX in interrupt, slow-lane rotation, fire-and-forget cap.
9. Ten nodes at 300 Hz; then 350 Hz; read utilisation from the corenode's own busy-time counter.

Hard gates unchanged: AS5047 soldered before any position work; phase order validated on a current-limited supply before calibration or sustained drive.

---

## 11. Open questions and what each blocks

| Question | Blocks | Level |
|---|---|---|
| **Node turnaround latency** (main-loop polled) | Whether two-in-flight hides it; if > ~100 µs the cycle grows by up to 10 × the excess | **[measure]** |
| **SimpleFOC Mini attachment** (own node / TIM1 on SPI2 pads / v1.1) — unchanged from the previous report | Class C exists at all | Design |
| **Jetson ↔ corenode link** (USB, UART, SPI?) and its rate | §7.1 interpolation; Jetson-loss detection threshold | Design |
| Which nodes carry foot load cells / output encoders | Class D count; +22 µs each | Implementation |
| Does the policy need per-cycle stiffness (`0x023–0x025`)? | +150 µs/cycle; class C → DLC 48 | Implementation |
| Exact effector mix per node (which six actuator nodes host the six non-shoulder servos) | Nothing on the protocol; the manifest | Implementation |
| Whether a separate G0 exists for acoustic wake | Power architecture only; the corenode must be FDCAN-capable regardless | Design (not bus) |

---

## 12. Changes this design requires in `docs/can-layer.md`

For the coordinator to apply; I have not edited `docs/`.

| § | Change |
|---|---|
| 0, scope note | Fleet is **10 nodes**, all with axis 0. Delete the "10 + 3 non-actuator" assumption; `aux` and `sense` profiles are not used on CATBOT. |
| 1, L0 | State that command frames are 29-bit (reply bit) and replies are 11-bit for ids ≤ 7. Add the §3.3 priority note. |
| 3.3 | Define the **fast pair**: per-cycle command = `cmd_a, cmd_b`; per-cycle readback = `meas_a, meas_b`; `cmd_c`, `meas_c/d` are slow-lane. |
| 3.4 | Re-bind so the fast pair is the loop-critical pair: `servo_rc` `meas_b` = 5 V current; `loadcell` `meas_b` = **contact flag**, `meas_d` = force rate. |
| 5.1 | Fast axis query is `0x000–0x003` only; `0x00D–0x00F` moves to the slow lane. Slow lane alternates two blocks on nodes whose block exceeds 64 B. Add the fire-and-forget per-cycle cap and the two-in-flight rule. |
| 5.2 | Replace the frame model with §3.1 (29-bit arbitration cost, CRC-17/21 split, DLC quantisation) and the table in §3.1. |
| 5.3 | Replace the budget table with §5.5; operating point 350 Hz / 68 % on one chain of 10. |
| 6 | Profiles are off the CATBOT path; `full` is the CATBOT image. |
| 7 | G1 = corenode-driven degraded mode on Jetson loss, fleet-state broadcast only; G2 documented but **not built**; add per-channel timeout behaviours and the 30 ms `default_timeout_s` recommendation. |
| 9 (new 9.5) | Physical layer: §2 of this document — sample points, **enable TDC for family 0**, termination rules, chain-not-star rationale. |
| 11 | Build order per §10; add turnaround measurement as step 2. |
| 12 | Close "10 vs 13"; close "brainstem G0 or G4" as "the corenode must be FDCAN-capable"; add the Jetson-link and turnaround questions. |

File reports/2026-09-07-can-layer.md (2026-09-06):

# FlexNode CAN layer — standing report

_2026-09-07. Explains and pressure-tests the v2 design in [`docs/can-layer.md`](../docs/can-layer.md); reasoning in [`notes/can-layer-design.md`](../notes/can-layer-design.md); board limits in [`notes/hardware-io.md`](../notes/hardware-io.md); flash in [`docs/flash-budget.md`](../docs/flash-budget.md). CATBOT facts are from the public site (`/projects/catbot/`, `/projects/flexnode/`)._

> **Nothing in this report, or in the spec it describes, has been exercised on a real CAN bus.** There is no adapter on the bench. Every byte count below is derived from the moteus source in this repo; every microsecond is arithmetic, not measurement.

## 1. What the layer is for, and the two rules

FlexNode makes a *node* — "one actuator plus whatever that joint needs to know about itself" — the unit CATBOT is composed from, and the same board a sellable product. The CAN layer turns thirteen boards into one machine, and it is the product's public API. Two rules follow and decide everything else:

1. **The register map is a stable, versioned, public interface.** A host written against block v2 works against every v2 node, forever. Registers are deprecated, never recycled; `0x0FF` is the version.
2. **What a node *is* may vary; what a register *means* may not.** Nodes differ in populated hardware and compiled features, never in semantics — and unpopulated, unconfigured and uncompiled are deliberately indistinguishable (all answer `kUnknownRegister`).

The layer is an addition, not a replacement: CAN-FD framing and the multiplex subframe protocol stay bit-for-bit stock moteus, which keeps `moteus_tool`, `tview`, the CAN bootloader and the Python library working. FlexNode lives in unused register space — the v1 node block at `0x080–0x0FF` and the new channel slots at `0x200+`.

## 2. The channel model, and why it beats v1

v1 assigned fixed registers per peripheral kind. That works for one robot and fails for a product: every new peripheral type or combination needs a new register range *and* a new host special case.

v2 inverts it. A node exposes up to eight **typed channel slots** at `0x200 + 0x10·slot` (slots 1–8 = `0x210–0x28F`). Every slot has the same 16-register frame: `type, caps, status, mode` at `+0..+3`, commands `cmd_a/b/c` at `+4..+6`, measurements `meas_a/b/c/d` at `+7..+A`, a `nonce` at `+B`, four type-specific. The host discovers each slot's `type` at boot and drives every channel through one driver. A new peripheral is a new enum value, not a new register range.

**The stride is the point.** Subframes address *consecutive* registers, so a full command is one write subframe and a full readback one read subframe. Here is the wire cost for a node with a BLDC axis, a load cell in slot 1 and an I²C encoder in slot 2, both on the fast lane. Subframe headers pack a count of 1–3 into the low two bits; a count of 4 costs a byte (`moteus_multiplex.h:646`). Registers above `0x7F` are two-byte varuints (`0x217` → `97 04`).

**Command frame, host → node 5, reply requested.** CAN id `0x8005`.

| # | Bytes | Meaning | Size |
|---|---|---|---|
| 1 | `01 00 0A` | write int8 ×1 @ `0x000`: mode = position | 3 |
| 2 | `07 20 pp pp vv vv tt tt` | write int16 ×3 @ `0x020`: position, velocity, ff-torque | 8 |
| 3 | `14 04 00` | read int16 ×4 @ `0x000`: mode, position, velocity, torque | 3 |
| 4 | `13 0D` | read int8 ×3 @ `0x00D`: voltage, temperature, fault | 2 |
| 5 | `14 04 97 04` | read int16 ×4 @ `0x217`: load-cell `meas_a..d` | 4 |
| 6 | `14 04 A7 04` | read int16 ×4 @ `0x227`: encoder `meas_a..d` | 4 |
| | | **Total → DLC 24** | **24** |

**Reply frame, node 5 → host.** CAN id `0x0500`.

| # | Bytes | Meaning | Size |
|---|---|---|---|
| 1 | `24 04 00` + 8 | mode, position, velocity, torque | 11 |
| 2 | `23 0D` + 3 | voltage, temperature, fault | 5 |
| 3 | `24 04 97 04` + 8 | force, d/dt, raw counts, **contact flag** | 12 |
| 4 | `24 04 A7 04` + 8 | angle, rate, —, magnet AGC | 12 |
| | | **Total 40 → DLC 48** (8 B padding on the wire) | **40** |

Three things the example teaches that the spec's prose does not:

- **Input-only channels have no command subframe.** The spec's "axis + 2 fast channels = 32 B / 32 B" assumed symmetric command+readback. A sensor channel costs 4 B in the request and 12 B in the reply.
- **DLC quantisation bites.** CAN-FD payloads step 24 → 32 → 48 → 64 (`fw/fdcan.cc:24`). The 40-byte reply goes out as 48; 33 to 48 bytes cost the same.
- **A four-register read is the wrong shape for the fast lane.** If the load cell's *contact flag* were `meas_b` (force-rate moved to `meas_d`), the fast read is two registers: `16 97 04` request, `26 97 04` + 4 reply — 7 B, not 12. Both channels reordered: command 22 → DLC 24, reply 30 → **DLC 32**. One DLC step per node per cycle, for a table edit. The design note's "do not reorder without redoing the bus budget" cuts both ways — this reorder *earns* the redo.

## 3. Cadence, lanes, and the bus budget

Two lanes, one master, strictly poll-response. **Fast lane:** every cycle, one command+query frame per node — stock axis command and query plus each fast channel. **Slow lane:** one node per cycle additionally dumps its full channel set and health; at 13 nodes and 325 Hz that is a 25 Hz refresh per node. Fire-and-forget writes (pixels, tare) fill idle. Promotion from slow to fast is a host schedule change; firmware is untouched.

The spec models a frame as ≈30 µs of arbitration-rate fields plus `(8N+43)` bits at 5 Mbit. **Two corrections are needed before the table is trusted.** `RoundUpDlc` quantises payloads as above. And the model assumes an 11-bit id, but the host sets `0x8000` on every frame that requests a reply (`lib/python/moteus/transport.py:344`) and the firmware sends any id ≥ 2048 as a 29-bit extended frame (`fw/fdcan.cc:323`) — so every fast-lane command is extended, as is every reply from a node with id ≥ 8. The 18 extra id bits plus SRR/IDE at 1 Mbit add roughly **+20 µs per frame** (stuff bits ignored). Recomputed, worst case, all frames extended, slow-lane pair excluded as the spec did:

| Configuration | Cmd / reply DLC | µs per node | 13 nodes @ 325 Hz | Spec said |
|---|---|---|---|---|
| axis only | 16 / 16 | 166 | **70 %** | 55 % |
| axis + 1 input channel (4-reg read) | 20 / 32 | 198 | **84 %** | 65 % |
| axis + 2 input channels (4-reg reads) | 24 / 48 | 230 | **97 %** | 75 % |
| axis + 2 input channels, 2-reg reads | 24 / 32 | 205 | **87 %** | — |
| 2 chains × 7, axis + 1 channel, 400 Hz | 20 / 32 | 198 | **56 %** | 52 % |
| 2 chains × 7, axis + 2 channels, 1 kHz | 24 / 48 | 230 | **161 %** | 130 % |

The spec's two structural conclusions survive, stronger than stated. **Two fast channels per node is the ceiling on one 13-node chain** — with real frame sizes even *one* on every node breaches the 65 % headroom rule. **1 kHz is unreachable on one chain and on two**; 400 Hz on two chains is the right target, and the RC servos are 50–330 Hz devices regardless. Splitting the chain remains the highest-leverage decision: nearly half the load, and fault containment free. Giving ids 1–7 to the nodes that matter most saves ~20 µs on each of their replies.

**Is the two-lane shape right for CATBOT's actual sensors?** Mostly. On a BLDC node the joint angle is already in the stock query (`0x001`), so the channels that earn a fast slot are foot contact, an output-side encoder where the 14:1 belt separates rotor from joint (the site does not say the knees have one), and the *command* side of servos and the SimpleFOC Mini. That is zero to one fast channel on most nodes and two on the shoulders — the budget worry is two nodes, not thirteen. One refinement: schedule each node at a rate divisor (1, 2, 4 … 13) instead of two fixed lanes. Servo-only nodes at half rate cost nothing in firmware and would pull a 13-node chain back under 65 %.

## 4. Host-loss autonomy: G0, G1, G2

The Jetson is "allowed to crash". Three graded answers, only the first mandatory:

- **G0 — independent timeout, always on.** Stock `servo.default_timeout_s` (0.1 s) drops the axis into timeout mode; channels go to `mode = 0`, which is why released is the boot default. No new protocol, no coordination, no shared failure. This is the floor and it is never disabled.
- **G1 — brainstem presence beacon.** A fire-and-forget broadcast to `0x7f` at ~10 Hz; nodes track beacon age in `0x087` and reduce limits when it goes stale. Under 0.1 % of the bus, no election, no node-to-node traffic. **Requires the brainstem to have FDCAN** — §9.
- **G2 — deputy.** If the beacon *also* dies, the node with the lowest non-zero `deputy_rank` waits `rank × stagger_ms` and broadcasts a canned safe sequence. Any host or brainstem traffic demotes it instantly; its authority expires after `authority_ms`.

**G2 is the most dangerous idea in the design, and it should be said plainly.** A node that can command its peers can do so *while it is wrong* — a stuck beacon-age counter, a duplicated rank, a half-dead node that believes the fleet is silent. Three constraints make it survivable and none may be relaxed for convenience: a whitelist of *reducing* actions only (fold, lower, relax, hold — never walk, never raise a limit); authority that *expires* back to G0; and a rank that defaults to 0 so nothing self-promotes. Two things the spec understates. Because moteus ignores the source field, a deputy's frames are indistinguishable from the host's — so **receivers cannot filter a rogue deputy**; a cheap belt-and-braces is to accept a non-host source only while the receiver's own `0x087` ≥ 2. And a broadcast cannot carry per-joint targets, so "fold" must be a *named posture* each node resolves from its own config — those per-joint angles need validating on the standing robot before G2 is ever enabled. Build G0 now, G1 when the brainstem exists, G2 only once CATBOT stands.

## 5. Node identity

A node carries three things that must not be conflated: a **CAN id** (bus address, `id.id`, 1–126), a **UUID** (immutable silicon serial, `0x150–0x153`), and a **name** (`flexnode.name`, 16 NUL-padded UTF-8 bytes at `0x0C0–0x0C3`). The name is in registers, not only a config string, because the text protocol is slow, unavailable to a minimal host, and absent exactly when the name is most wanted — in a fault dump. Four consecutive int32 registers mirror how moteus publishes its UUID, so a name is one subframe, read once at enumeration. The host should assert id, UUID and name against a fleet manifest at boot, alongside profile id and build hash — one refusal catches both a board swapped between joints and a mixed-image fleet. Add `deputy_rank` uniqueness to the same assertion.

## 6. Mapping onto CATBOT

Published fleet: 4× GIM8108-8 "sagittal hips", 6× 5010 knees (14:1 belt), 2× head gimbals on a SimpleFOC dual driver, 7× DS3235/DS3230 servos "hung off node aux ports" — 19 DoF. Aditya's 2026-09-07 statement puts a GIM 8108-8 *and* a SimpleFOC Mini on each of two **shoulder** nodes. I read the shoulders as two of the four GIM8108 nodes (front hips); if they are additional, the site's count of four is wrong. Whether the shoulder Minis *are* the head gimbal driver or a separate pair is stated nowhere.

| Node | Axis 0 | Channels it would declare | Fast-lane load |
|---|---|---|---|
| `shoulder_fl`, `shoulder_fr` | GIM8108-8 | `bldc_ext` (Mini) + `enc_i2c` (Mini feedback) + `imu` + `pixel` + `rail_5v`; one adds `servo_rc` (DS3235), the other has spare capacity ("load cell / RGB") | 2 command channels: cmd 48 / reply 48 — the two heaviest nodes on the bus |
| `hip_rl`, `hip_rr` | GIM8108-8 | `imu`, `pixel`, `rail_5v`, possibly `loadcell` | 0–1 |
| `knee_*` ×6 | 5010 + belt | `imu`, `pixel`; output-side `enc_i2c` and a foot `loadcell` are *plausible but unstated* — which node the foot wires to is undocumented | 0–1 |
| servo nodes | — | `servo_rc` ×1 (+ optional `enc_i2c` feedback), `imu`, `pixel`, `rail_5v` | 1 |

**The 10-vs-13 discrepancy, again.** Ten BLDC actuators get a FlexNode each; the site says thirteen nodes. If 13 = 10 + 3 aux nodes, only 3 of the 7 servos can have dedicated nodes and the other 4 ride on actuator nodes (one is the shoulder's DS3235; three are unknown). If all 7 servos get dedicated nodes, the fleet is 17, and every budget line above gets roughly 30 % worse. This changes the profile mix and the chain split, not the protocol — but it must be settled before the bus is laid out. (The `aux` profile compiles `servo_rc` ×2 against a one-servo-per-node rule; harmless, but worth aligning.)

## 7. Learnings worth keeping

- **`0x7f` broadcast already works.** `fw/moteus.cc:307` accepts `prefix<<16 | 0x7f` on standard and extended filters. G1 and G2 needed no protocol invention.
- **moteus ignores the frame source field**, so a deputy needs no receiver-side change — and that is exactly why a receiver-side sanity check is worth adding (§4).
- **Profiles solved a problem measurement then dissolved.** They were the release valve for a 16.8 kB flash budget; three drive-path-free changes measured −84 kB and a 48.7 kB hole in the linker map was labelled "currently unused". Profiles survive only as a safety/product choice.
- **The PCA9685 was withdrawn** because it optimised a per-node resource (one pulse pin) before asking how the mechanical layout distributed the load (one servo per node, seven nodes). Ask the layout question first.
- **An absent entry in a vendor table is not an absent capability.** "PC13 has no timer" was true of the moteus aux table, false of the silicon (TIM1_CH1N, TIM8_CH4N). Likewise motor PWM is on TIM5, not TIM2 — the conclusion survived, the reasoning did not.
- **Frame cost is not payload length.** DLC steps and the extended-id bit are each worth on the order of 20 % on a small frame; both were missing from the budget (§3).

## 8. Where I disagree, or would push

- **Fix the budget table before anything is scheduled against it** — DLC rounding, extended ids, asymmetric sensor channels. The conclusions hold; the margins do not exist.
- **Put loop-critical measurements first.** Make `meas_a/meas_b` the two registers the fast lane wants for every type (load cell: force, *contact*), so a fast read is a 3-byte request and 7-byte reply. Cheaper to decide now than after the map is public.
- **Eight slots is exactly v1.0's physical ceiling; the address space should not be.** A shoulder with Mini, its encoder, a servo, load cell, IMU, pixel, rail sense and ToF is eight. Reserve `0x210–0x30F` for 16 slots now (free), implement 8, and decide whether onboard fixtures (`imu`, `pixel`, `rail_5v`) consume slots at all — they have v1 aliases, and they eat three of eight on every node if they do. Define `0x085` as *highest populated slot*, not a count, or enumeration stops at the first gap.
- **The 16-register stride suits control-shaped peripherals, not array-shaped ones.** The `imu` binding row is all dashes because six axes do not fit four `meas` registers; its data lives in the v1 alias. Say so, or a second IMU (the head has one) cannot be a channel.
- **Take profiles off CATBOT's critical path.** Space is solved, `full` fits everything, the site already promises "one firmware · N configs", and one image removes the mixed-fleet hazard §6.4 exists to catch. Keep the mechanism for motor-less retail SKUs later.
- **`notes/open-questions.md` is stale** — §2 still says "PC13 has no timer" and "TIM2", §2b still recommends the PCA9685; both contradicted by `hardware-io.md`. Edit in place, as its header asks.

## 9. Open questions, and what each blocks

| Question | Blocks | Level |
|---|---|---|
| **How does the SimpleFOC Mini attach?** Own CAN node (must be FD, not classic), TIM1 on the SPI2 pads (costs SPI expansion; CHxN + MOE setup; software sin/cos, never the shared CORDIC; PB14 `kNC`), or defer to v1.1 | `bldc_ext`, the shoulder nodes, any v1.1 respin | **Design** |
| **Brainstem: STM32G0 or G4?** G0 has no FDCAN; the site says both | G1 beacon, two-chain topology, whether 400 Hz is reachable at all | **Design** |
| 10 vs 13 (or 17) nodes | Chain split, profile mix, bus budget | Implementation |
| Is the Jetson on the bus, or only behind the brainstem? | Two masters or one; where the G1 beacon originates | Implementation |
| Load-cell ADC part (NAU7802 recommended) and which node the foot wires to | `loadcell` channel, contact thresholding | Implementation |
| Do knees carry an output-side encoder? | `enc_i2c` on knee nodes, fast-lane count | Implementation |
| Tunnel throughput for the 84 kB ToF blob × 13 nodes | ToF bring-up time | Implementation |
| **A CAN adapter** | Every line of this report | Bench |

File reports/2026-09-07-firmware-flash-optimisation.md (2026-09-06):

# Firmware flash optimisation — what to do, and what not to delete

_Standing report for Aditya. Measured 2026-09-07 01:20–02:40 IST against the `bee0685` image
(app 437,808 B, 16,848 B free). Full numbers and per-object tables live in
[`docs/flash-budget.md`](../docs/flash-budget.md); this report is the decision document._

## The short version

You do not have to remove a single driver to solve the flash problem.

Three build-level changes, none of which touches the motor drive path and none of which deletes
any functionality, were measured by real builds of an untouched copy of the tree:

| Change | Measured saving | What it deletes |
|---|---|---|
| Link against newlib-nano (the small C library) | −33,916 B | nothing |
| Stop the C++ exception runtime from being linked | −12,316 B (less on top of nano) | nothing |
| Compile one non-realtime file for size instead of speed | −50,144 B | nothing |
| **All three together** | **−84,028 B → 353,780 B image, 100,876 B free** | **nothing** |

That is six times the space you have today, before touching a line of moteus's driver code.
There is a further ~47 kB of physically unused flash between the vector table and the bootloader
that a linker-script change can reclaim, also without deleting anything.

Driver removal is an optional, last-resort lever. Everything measurable in that category adds up
to **19,242 B** — less than a quarter of what the build-level changes give — and it is the only
lever that makes future merges from upstream moteus harder. My recommendation, agreeing with the
coordinator: **keep every driver, take the 84 kB, revisit only if you ever actually run out.**

## What the "removable" drivers actually are

You said: _"I barely understood what drivers are being removed and why … for all we know it does
most of what we're trying to build anyway."_ That instinct is partly right, so here is each
candidate in plain terms. "Could FlexNode use it" means: is there a plausible CATBOT configuration
where this code earns its place.

**iC-PZ (6,637 B).** A driver for the iC-Haus iC-PZ, a high-resolution *optical* absolute encoder
chip that reads a reflective code disc over SPI and has its own calibration register set. It is
used in precision industrial and research actuators. FlexNode's planned encoders are magnetic
(AS5047 onboard, AS5600-class or MT6701 on I²C); an optical disc assembly is not on the roadmap.
This is the one candidate with no plausible CATBOT use. Losing it loses only iC-PZ support. It is
also the cleanest cut technically (its own telemetry channel, no interrupt entanglement).

**BiSS-C (3,832 B plus an unmeasured share of shared code).** Not a chip but a serial *protocol*
used by industrial absolute encoders from Renishaw, RLS, Hengstler and many Chinese servo-encoder
vendors. moteus implements it by bit-banging with a timer and DMA. Nothing in the CATBOT parts
list speaks BiSS-C, and the encoders you are considering (AS5600, MT6701, AS5047) do not. Losing it
loses the ability to bolt an industrial BiSS-C encoder onto an aux port later. Plausible but
unlikely for this robot.

**MA732 (1,040 B).** A driver for the MPS MagAlpha MA732, a cheap, popular SPI magnetic encoder in
the same class as the AS5047. **This one is potentially useful.** If a future joint encoder on the
SPI-capable aux pins ends up being a MagAlpha part — a very normal choice — this 1 kB is exactly
the code you would want. Keep it.

**Quadrature, software and hardware-timer (1,816 B).** Reads incremental A/B (ABZ) pulse trains —
the output mode of classic incremental encoders and also an *alternate output mode* of both the
AS5047 and the MT6701. **Potentially useful**: it is the natural way to give a second axis (for
example the SimpleFOC Mini's motor) a position feed without another SPI bus. Keep it.

**UART "serial" mode — the fdcanusb-over-UART server (5,917 B).** Lets a host computer talk the
same ASCII protocol that the fdcanusb CAN adapter speaks, but over a plain UART on an aux pin. In
other words: `moteus_tool` and tview without a CAN adapter. **You currently have no CAN adapter on
the bench.** If any USART-capable aux pin is reachable on FlexNode (the stock table lists PB3/PB4/
PA15 for USART2 and PB8/PB9 for USART3, the latter being the I²C bus, which becomes free on a node
without the IMU), this driver is a bring-up tool, not dead weight. Keep it, and consider using it.

**The rest — hall, index, sine/cosine, PWM-input, step/dir, AS5048, MA600, AksIM-2, CUI AMT21/22,
Orbis.** These have no standalone code at all any more: the linker's dead-code removal and the
compiler's inlining have already folded them into shared functions, so their individual cost is
*unmeasured and unmeasurable without per-driver experimental builds*. Several are plausibly useful
(hall sensors as a commutation fallback, PWM-input for the PWM mode of AS5600/MT6701, AS5048B as an
I²C encoder sibling of the AS5600, MA600 as MA732's sibling). Treat them as free.

Net: of the five measurable candidates, three (MA732, quadrature, UART serial) are things CATBOT
might genuinely want, one (BiSS-C) is unlikely but harmless, and one (iC-PZ) is dead weight worth
6.6 kB. Your worry was justified.

## Decision table

| Option | Space gained | Capability lost | Merge cost with upstream | Verdict |
|---|---|---|---|---|
| **Keep every driver; apply the three build-level changes** | 84,028 B measured (100,876 B free); +~23–47 kB more from the linker gap | none | none — 2 lines in `fw/BUILD`, one new file, one scoped pragma | **Default. Do this.** |
| Cut the obvious (iC-PZ only) | +6,637 B on top | iC-PZ optical encoders | small, contained edit in `aux_port.h` | Only if you are ever within 7 kB of the wall |
| Cut everything measurable (iC-PZ, BiSS-C, MA732, quadrature, UART serial) | +19,242 B on top | MagAlpha SPI encoders, ABZ incremental input, serial bring-up without CAN, BiSS-C | medium and permanent: exhaustive `switch`es in upstream files, every future merge conflicts | Not recommended |
| Cut the inlined drivers too | unmeasured | hall fallback, PWM-mode encoders, AS5048/MA600 | high; touches the position-sampling interrupt path | Do not |

I agree with the coordinator's read. The only refinement: iC-PZ is a legitimate future cut, but it
buys 6.6 kB against a 100 kB margin, so it is not worth the merge friction today.

## The three build-level changes, in enough detail to apply

**1. newlib-nano.** The firmware currently links the full-size newlib C library because the
`nanospecs` toolchain feature exists in `rules_mbed` but was never enabled for the `moteus`
target. Nano is the same library built for size: its `printf` family, `strtod`, `malloc` and
locale support are a fraction of the full versions. The change is two lines on the `moteus`
target in `fw/BUILD`: add `"nanospecs"` to `features`, and add `linkopts = ["-Wl,-u,_printf_float"]`.

> **Why `-u _printf_float` is mandatory.** Nano's `printf` leaves out floating-point formatting
> unless you explicitly ask for it. moteus prints *every* float — `conf get`, `tel get` in text
> mode, `moteus_tool --dump-config` and `--restore-config`, tview — through `snprintf("%g")`.
> Without the flag the build succeeds, the image is 4,880 B smaller, and every float comes out
> wrong. It is a silent correctness bug, not a build error. (`_scanf_float` is not needed; nothing
> uses `scanf`.)

Verified in the variant build: float printing is present and the C++ exception runtime largely
disappears as a side effect, because nano's C++ library does not drag it in.

**2. The throw-stub file.** Although everything compiles with exceptions disabled, three helper
functions from the standard library (`std::__throw_out_of_range_fmt`, `__throw_length_error`,
`__throw_logic_error`, referenced from `moteus.cc` and two mjlib objects) pull in the whole
exception, RTTI, `std::string` and even `std::random_device` machinery from the prebuilt library.
A new FlexNode-owned file `fw/flexnode_nothrow_stubs.cc` defines those functions (plus the
`optional`/`variant` variants) as `[[noreturn]]` traps. Under `-fno-exceptions` the existing
behaviour on that path is already "terminate", so nothing observable changes. Add the file to
`MOTEUS_SOURCES` in `fw/BUILD`; no upstream file is edited.

**3. Size-optimise one file: `fw/moteus_controller.cc`.** All firmware files are built with `-O3`
(speed) via `features = ["speedopt"]`. That is right for the FOC interrupt in `bldc_servo.cc`. It is
wrong for `moteus_controller.cc`, which is command handling, register dispatch and the code that
serialises config and telemetry structures. Building just that file for size measured −50,144 B —
the single largest saving — and revealed that most of the apparent "driver bloat" was the speed
optimiser inlining the same configuration code over and over.

> **The fragility, and the remedy.** The measurement used a file-wide `#pragma GCC optimize("Os")`.
> The big interrupt routines that live in this file as templates came out byte-identical — but only
> because identical copies also exist in `bldc_servo.o`, and the linker happened to pick those
> `-O3` copies first. A few small interrupt helpers that exist *only* in this file (including the
> AS5047 SPI transfer used during position sampling) did get size-optimised. Do not rely on link
> order. Apply the pragma with `#pragma GCC push_options` / `pop_options` around the register
> read/write and command-handling code only, or split the file, and have the position-sampling
> path reviewed before the first motor spin.

Applying a size flag to the whole firmware, incidentally, does not even compile
(`bldc_servo_control.h:1137`, a section-type conflict) and would be wrong anyway.

**4. The flash gap (optional, no code).** Vectors occupy 472 B at 0x08000000 and the bootloader
starts at 0x0800C000; the 48,680 B between are unused — the linker script even labels them so.
Extending the `FLASH_ISR` region and placing read-only data inside the `.isr_vector` output section
reclaims up to ~47 kB. The one rule: it must stay *inside* `.isr_vector`, because `moteus_tool`
flashes sections by name from a fixed list and would silently skip a new one. Details in
[`docs/flash-budget.md`](../docs/flash-budget.md).

## What we learned

- **Measure before optimising.** Two reasonable intuitions were wrong in one evening: "the unused
  encoder drivers are the big win" (they total 19 kB; the build flags total 84 kB) and "the debug
  console is disposable" (see below).
- **Dead-code removal had already done the driver pruning.** `--gc-sections` has been on all
  along. Anything genuinely unreferenced was never in the image; what remains is referenced by
  configuration switches, and most of *that* was `-O3` inlining rather than driver logic.
- **An unused-looking thing can be load-bearing.** `board_debug` looked like a 13.6 kB developer
  console. `moteus_tool` uses its `d flash` command to enter the CAN bootloader, and its `d cal`
  family to calibrate. Removing it would have broken both `--flash` and `--calibrate`.
- **Serialisation boilerplate is large and mostly non-negotiable.** Every config or telemetry
  struct costs 2–8 kB of generated schema, text and binary code. Reducing struct field counts
  (including in FlexNode's own LED and register code) is a cheaper lever than deleting drivers.
- **The flash budget was the constraint shaping the CAN-layer design.** It no longer is; per-role
  images stay only as a safety property, not as a space workaround.

## What is unmeasured, and what it would take

- The split of the 36,176 B of aux-port serialisation between never-used and needed devices.
  Needs one experimental build per removed device — a real edit each, because the switches are
  exhaustive under `-Werror`.
- The individual cost of the fully inlined drivers (hall, index, sine/cosine, PWM-input, step/dir,
  AS5048, MA600, AksIM-2, CUI, Orbis). Same method.
- The cost of a second commutation path for the SimpleFOC Mini: an analogue-based budget of
  ~10–13 kB, not a build.
- CPU headroom for that second loop. The firmware has no interrupt-timing instrumentation; the only
  runtime metric is `system_info.idle_rate`, readable over SWD today or via CAN later.
- **Nothing in this report has been validated on a running board.** Every figure is from builds.

## Appendix — symbol-level evidence (for future sessions, not for the decision)

- Image composition: `.text` 404,428 · `.ARM.extab` 276 · `.ARM.exidx` 448 · `.data` 2,696 ·
  `.ccmram` 29,960 (hot ISR code copied to CCM RAM at boot; unreclaimable).
- Largest objects: `moteus_controller.o` 129,541 · `bldc_servo.o` 104,475 · libc 42,153 ·
  `drv8323.o` 33,160 · libmbed 28,234 · `moteus.o` 19,383 · `ws2812_led.o` 13,832 ·
  `board_debug.o` 13,568.
- Driver symbols: `SerializableHandler<IcPz::Status>` family 6,637; `UartFdcanusbMicroServer`
  5,917; `BissC` ctor 1,312 + `ISR_ProcessRead` 1,056 (CCM) + rest 3,832; `Stm32Quadrature` 1,816;
  `MA732::SetRegister` 1,040.
- Under `-Os`: `AuxPort::HandleConfigUpdate` 13,636 → 4,788;
  `AuxStatus::Serialize<BinarySchemaArchive>` 4,764 → 604.
- Variant ELFs, map and scripts are in the gitignored `tools/bench/out/` (`_scratch_V*.elf`,
  `_moteus.map`, `_scratch_build*.sh`, `_relink_map.py`).

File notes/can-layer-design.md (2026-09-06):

# CAN layer — why it is shaped this way

_Design decisions and their reasoning, recorded 2026-09-07 01:35–02:20 IST._

The spec itself is [`../docs/can-layer.md`](../docs/can-layer.md) (v2). This file holds the
*reasoning* — what was considered, what was rejected, and what would have to change to revisit a
decision. Read this before proposing a redesign.

## The framing that drives everything

Aditya, 2026-09-07: FlexNode exists to *"make the development of catbot infinitely easy with clever
engineering, and in the process get a sellable flexible module node too — and the can layer is a
core enabler of it."*

Two consequences, and nearly every decision below follows from one of them:

1. **The register map is a public, versioned API**, not an internal detail. It must not change
   meaning between boards, builds or firmware revisions.
2. **What a node *is* may vary; what a register *means* may not.**

## Decisions

### Extend moteus, don't invent a protocol — kept from v1

L0 (CAN-FD framing, `(source<<8)|dest`) and L1 (multiplex subframes) stay bit-for-bit stock. That
buys `moteus_tool`, `tview`, the CAN bootloader and the Python library for free, and it means a
stock moteus host sees a working moteus controller. FlexNode is purely an L2/L3 addition in unused
register space. **Revisit only if upstream claims 0x080–0x0FF**, which would be visible as a merge
conflict long before it broke anything.

### Typed channel slots, replacing v1's fixed per-peripheral registers

v1 hard-assigned registers per peripheral kind. That works for one fixed robot and fails for
*"any accommodatable combination of encoders, sensors or digital sensors."* Every new peripheral
would have needed a new register range and a new host-side special case.

Slots invert it: the host discovers a list of typed channels and drives them all through one
uniform 16-register frame at `0x200 + 0x10·slot`.

> The stride is the whole point, and it is worth understanding before touching the layout.
> Subframes address **consecutive** registers, so a full channel command is *one* write subframe
> (3× int16 at `+0x4`) and a full readback is *one* read subframe (4× int16 at `+0x7`). Reordering
> the frame to group fields "logically" would silently double the subframe count and the bus cost.
> **Do not reorder without redoing the bus budget.**

The v1 block 0x080–0x0FF is **retained verbatim** — it is flashed, documented and public — and
reinterpreted as the "well-known view", aliases onto the first channel of each type.

### One image per profile, config within a profile

v1 said "one image, thirteen configs". Aditya, 2026-09-07: *"hardware changes can neither be made
at runtime, so no hot-plugging and reflashes on hardware changes are fully acceptable."*

The rule that keeps this from wrecking the product story: **a profile changes what is compiled,
never what a register means.** An uncompiled feature answers `kUnknownRegister`, exactly as
unpopulated hardware does — so the host cannot tell the difference and does not care. One host
implementation drives every profile.

> Gotcha, 2026-09-07 02:05 IST: profiles were designed as the **release valve for the flash
> budget**, and then the flash budget turned out not to be a problem — see
> [`flash-findings.md`](flash-findings.md). **Profiles are no longer load-bearing for space.**
> They stay in the design because a motor-less node that never links the FOC stack is a *safety
> property* and a product decision. Don't let anyone reintroduce them as a byte-count argument.

Mixed-image fleets are the real hazard of build-time specialisation, so nodes report profile id
(0x083) and build hash (0x084) and the host refuses a fleet that isn't what it was tested against.

### Host-loss: three graded levels, G0 always on

The Jetson is explicitly *"allowed to crash"*. A 4.8 kg machine on ten torque-producing joints
needs a defined answer to *commands stopped arriving*, and that answer must not depend on the thing
that died.

- **G0** — stock `servo.default_timeout_s` watchdog → timeout mode. Free, no coordination, no
  shared failure mode. **Always on, never disabled.** Everything else is an optimisation on top of
  a system that is already safe.
- **G1** — brainstem presence beacon, fire-and-forget broadcast, ~10 Hz, <0.1 % bus. No election,
  no node-to-node protocol, no unsolicited transmission by any node.
- **G2** — config-gated deputy. The **only** unsolicited transmit in the design.

The enabling discovery, 2026-09-07 01:05 IST: **destination `0x7f` is a broadcast every node
already accepts** — `fw/moteus.cc:307`, filters 1 and 3 accept `prefix<<16 | 0x7f` for both
standard and extended frames. Nothing had to be invented. Also `can.prefix` namespaces a bus, which
is how two chains stay separate.

Moteus does not inspect the source field of a frame, so a deputy's commands are accepted as
ordinary commands with **no firmware change on the receiving side**.

> **G2 is the most dangerous idea in this design.** A node that can command its peers can do it
> while wrong. Three constraints make it survivable and **none of them may be relaxed for
> convenience**: (1) the command whitelist contains only *reducing* actions — it can fold, lower,
> relax, hold; it cannot walk and cannot raise a limit; (2) deputy authority **expires**, falling
> back to G0; (3) `deputy_rank` defaults to 0 on every node, so nothing self-promotes out of the
> box. Election is by **staggered rank**, not arbitration — simpler, and two deputies cannot
> coexist.
>
> Build order: G0 now, G1 when brainstem firmware exists, **G2 only once CATBOT actually stands.**

### Node identity is three separate things

CAN id (address), UUID (silicon serial, `0x150`–`0x153`, immutable), and **name** (human-meaningful
role). Aditya asked for the name on 2026-09-07. It is 16 NUL-padded UTF-8 bytes at `0x0C0`–`0x0C3`,
deliberately mirroring how moteus publishes its UUID — four consecutive registers, so a whole name
reads in one subframe.

Registers rather than a config string over the text protocol, because the text protocol is slow,
isn't available to a minimal host, and would make the name unavailable exactly when it is most
wanted: in a fault dump.

## Rejected

| Idea | Why not |
|---|---|
| A bespoke CATBOT packet format | Throws away moteus tooling and the bootloader for a bus that is only ~65 % loaded anyway |
| Nodes free-running telemetry at intervals | Unschedulable worst-case latency and arbitration storms. The master owns all timing; "report at intervals" is the *master's* schedule |
| Fixed per-peripheral registers (v1) | Doesn't survive arbitrary peripheral combinations |
| **PCA9685 expander for 7 servos** | **Withdrawn 2026-09-07** — the servos hang off 7 *different* nodes. Solved a problem that didn't exist. See [`hardware-io.md`](hardware-io.md) |
| 1 kHz on a single 13-node chain | Measured at 92–130 % bus load. Not reachable. 400 Hz on two chains is the right target |
| Fast-lane IMU on every node | Two fast channels per node is the practical ceiling; IMU belongs on the slow lane except on the 2–3 nodes feeding state estimation |

## Numbers worth not re-deriving

Frame time (CAN-FD, 11-bit id, BRS, 5 Mbit data): ≈30 µs of arbitration-rate fields + (8·N + 43)
bits at 5 Mbit. 16 B ≈ 64 µs, 32 B ≈ 90 µs, 64 B ≈ 141 µs.

| Configuration | Load |
|---|---|
| 13 nodes, axis + 1 fast channel, 325 Hz | 65 % ✓ |
| 13 nodes, axis + 2 fast channels, 325 Hz | 75 % ⚠ |
| 13 nodes, axis + 2 fast channels, 400 Hz | 92 % ✗ |
| 2 chains × 7, axis + 2 fast channels, 400 Hz | 52 % ✓ |
| 2 chains × 7, axis + 2 fast channels, 1 kHz | 130 % ✗ |

Keep steady-state ≤65 %. Splitting front/rear buys nearly 2× **and** fault containment — the
highest-leverage topology decision available.

## Still open

See [`open-questions.md`](open-questions.md). The two that block design work rather than
implementation:

1. **How does the SimpleFOC Mini attach?** Shoulder nodes need it *simultaneously with* their own
   GIM 8108-8, so it is an addition to the onboard FOC axis, not an alternative.
   [`hardware-io.md`](hardware-io.md) has the TIM1 candidate path.
2. **Brainstem: STM32G0 or G4?** **G0 has no FDCAN.** If the brainstem is to be the Phase-B
   realtime bus master it must be a G4. This decides whether the two-chain topology — the thing
   that buys 400 Hz — is reachable at all.

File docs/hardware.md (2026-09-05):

# FlexNode — Hardware

Status: **v1.0, first article assembled and booted 2026-09-06.** Power tree (5 V / 3.3 V) and MCU boot-from-flash validated; the encoder is not yet soldered and the power stage has not been energized. Values below reflect the schematic/BOM committed to fab — note the as-built R30 deviation in [firmware.md](firmware.md).

## Block diagram

```
        ┌──────────────── CAN-FD bus (daisy-chain) ────────────────┐
        │                                                          │
   [J3 in]──┬──[TCAN334G]──FDCAN──┐                          [J4 out]
            │   (120Ω term @      │                                
       120Ω bridge   leaf nodes)  │                                
                                  │                                
   V+ (10S) ─┬─[LGS5160C buck]─5V─┼─[MCP1700]─3V3───────┐          
             │                    │                     │          
             │              ┌─────┴─────┐          ┌────┴─────┐    
             │              │ STM32G4   │──SPI────│ AS5047P   │    
             │              │  (FOC +   │          │ encoder   │    
             │              │  fusion)  │──I²C─┬──[LSM6DS3 IMU]│    
             │              └─────┬─────┘      └──[VL53L7CX ToF]    
             │                    │ SPI                            
             │              ┌─────┴──────┐                         
             └──────────────│ DRV8353S   │──gate──[6× BSC016N06NS]─── 3-phase motor
                            └────────────┘         ↑ shunts → current sense
                                                                    
   PC13 ── servo/LED out ── [50 mΩ shunt] ── 5 V current sense (PB11)
   PF0  ── WS2812B status LED
```

## Power tree

| Stage | Device | In → Out | Notes |
|---|---|---|---|
| Motor bus | — | battery V+ | 10S-class, feeds FET bridge + DRV VM directly |
| Aux buck | LGS5160C | V+ → 5 V | 65 V-rated sync buck, ~426 kHz, internal comp, hiccup SCP/OCP, EN tied to V+ |
| Logic LDO | ME6216A33M3G | 5 V → 3.3 V | MCU + sensor rail; MCP1700-footprint-compatible (SOT23-3: VSS/VOUT/VIN), 300 mA |
| Buck output cap | 3× 10 µF (25 µF eff.) | — | transient-driven; feed-forward Cff optional/DNP |

The buck EN is tied directly to V+ (no UVLO divider). Feedback: R15 (1 MΩ) / R17 (249 kΩ), RFREQ = 200 kΩ, PG pull-up R16 (100 kΩ). See the LGS5160C notes in the project datasheet folder for the full passive spec.

## Motor stage

- **FETs:** 6× BSC016N06NS (60 V / 1.6 mΩ, TDSON-8). Chosen over moteus's TPH1R204PL for the higher voltage headroom at 10S; footprint changed to TDSON-8 to match.
- **Gate drive:** DRV8353S, 3-PWM mode (low-side inputs tied to `MOTOR_HIZ`), 7.5 Ω gate resistors + BAT41 clamp diodes as in moteus. Gate-drive currents inherited from the r4.11 (`hw_version = 8`) register set — functional for the BSC016N06NS, not separately re-tuned.
- **Current sense:** three in-line shunts → DRV current-sense amps (SOA/SOB/SOC) → RC filter → MCU ADC (PB0/PB1/PB2). ⚠️ Schematic note: the CUR1/CUR3 net *labels* are swapped relative to moteus (label CUR3 = winding A, CUR1 = winding C) but the copper connectivity is stock — when bench-probing, trust pins, not labels.
- **Copper:** 4-layer, 1 oz all layers. Validated against CATBOT's real phase currents (nominal ~2–5 A, transient peaks to ~25 A stall); the actuator thermally limits well before the board does, with comfortable FET margin. 1 oz also allows the tighter JLCPCB clearance that 2 oz would forbid.

## Rotor feedback

- **AS5047P** on-axis magnetic encoder, SPI. **Chip-select moved to PC6** (moteus used PB11). Mounted on the **back layer** (single-sided assembly build).

## Communications

- Single **TCAN334G** CAN-FD transceiver (moteus's optional second transceiver footprint is staggered/DNP and left unpopulated).
- **Daisy-chain**: connectors J3 (in) and J4 (out) share the differential pair, so nodes chain node-to-node on one bus.
- **Termination**: a 120 Ω resistor selectable by a back-layer bridge pad — closed only on the two **leaf (end) nodes** of the chain; open (unterminated) on all interior nodes. Do **not** terminate every node.
- **Protection**: SZNUP2105 dual TVS across the pair; common-mode choke on the transceiver side.
- **Protocol, cadence, and bus budget**: see [can-layer.md](can-layer.md) — moteus register protocol extended with the FlexNode block (0x080–0x0FF), two-lane poll-response scheduling, and per-rate utilization math.
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

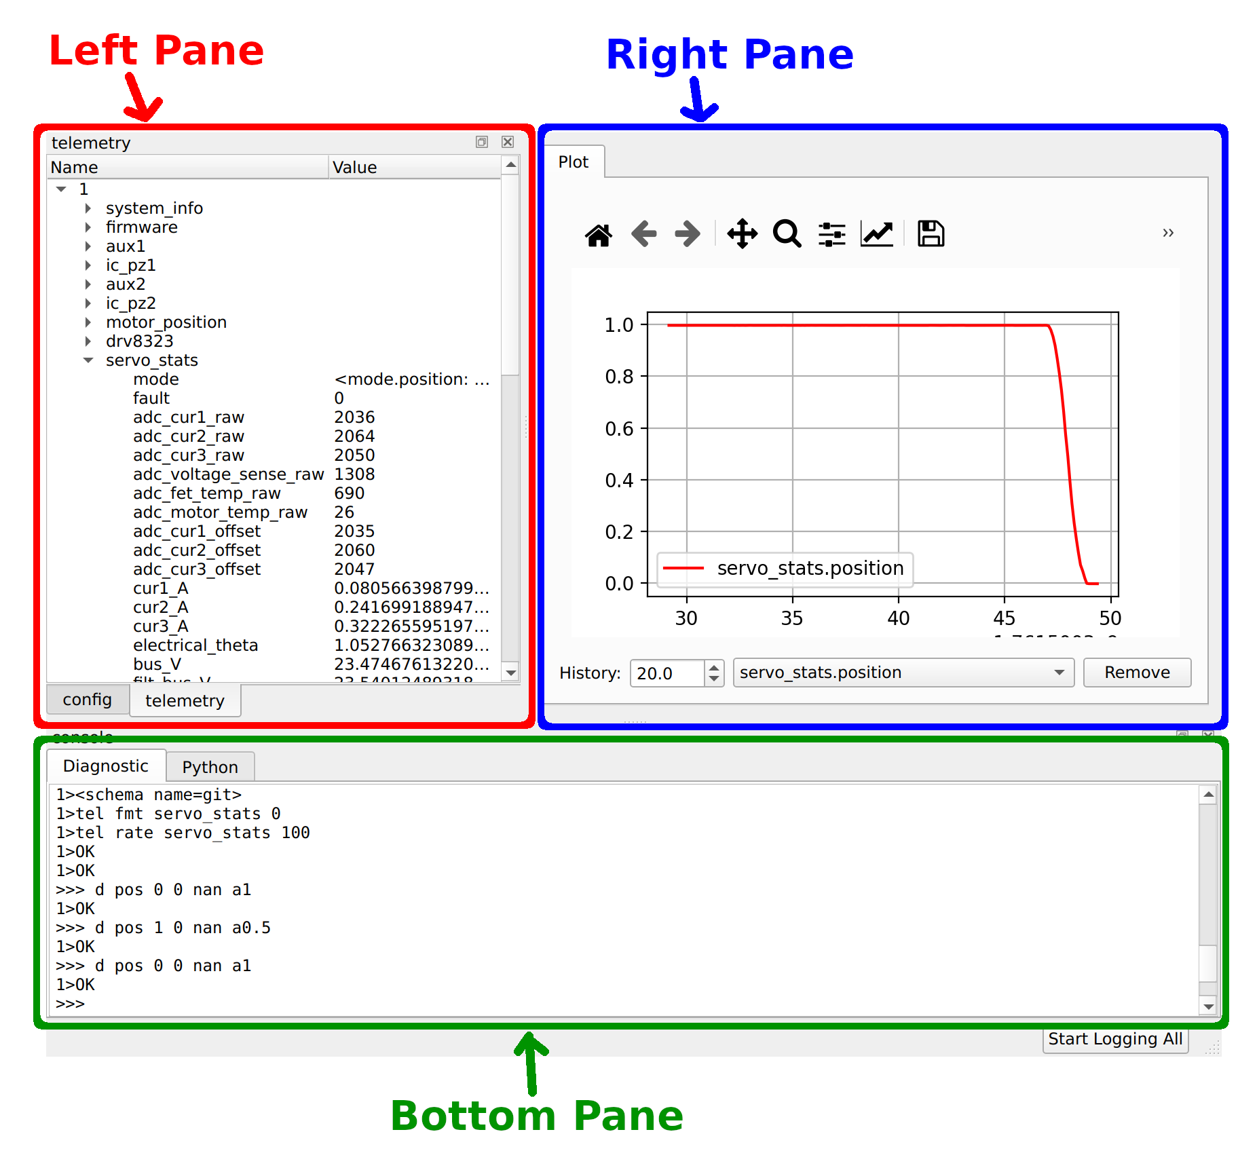
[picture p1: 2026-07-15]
moteus-r4-parent/docs/guides/images/tview-overview.png

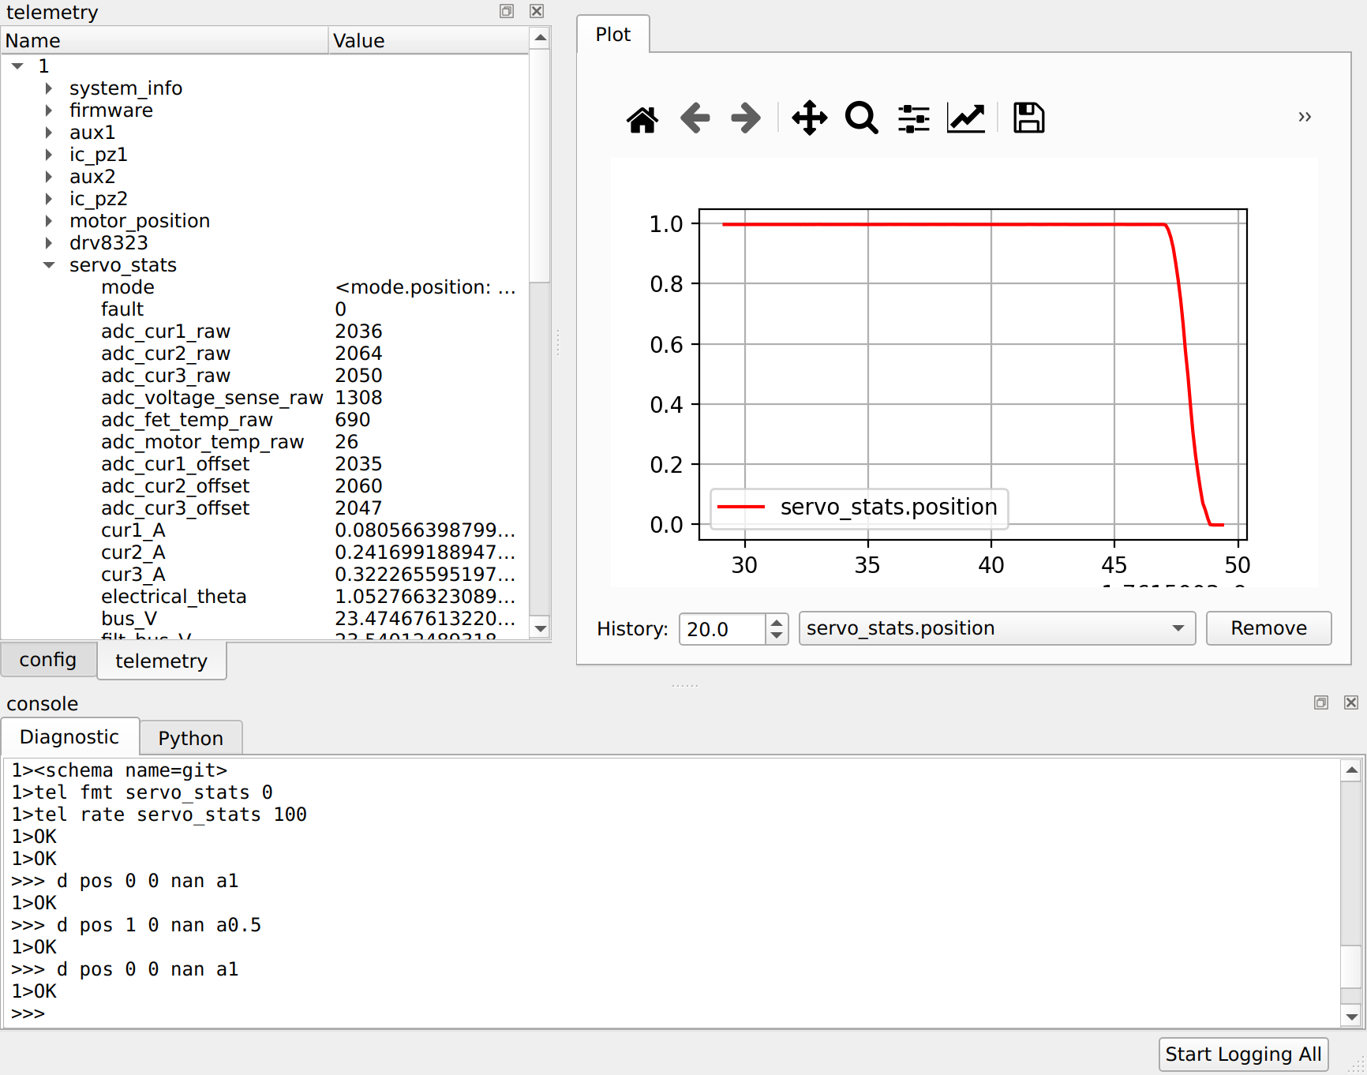
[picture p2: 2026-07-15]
moteus-r4-parent/docs/guides/images/tview-overview-orig.png

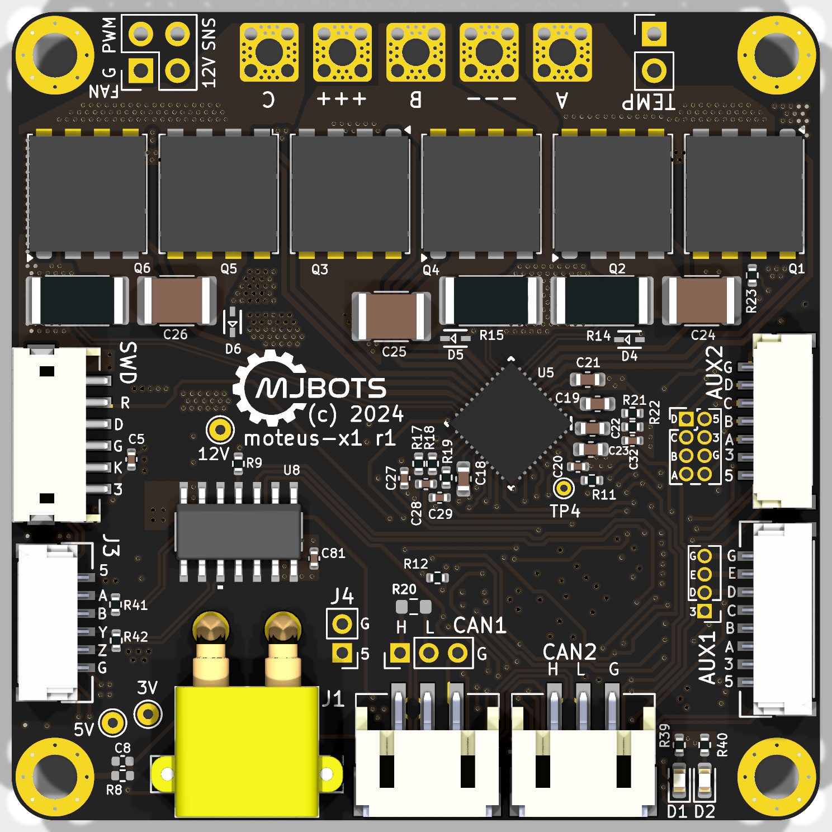
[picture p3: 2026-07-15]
moteus-r4-parent/docs/reference/x1/moteus-x1-base.png

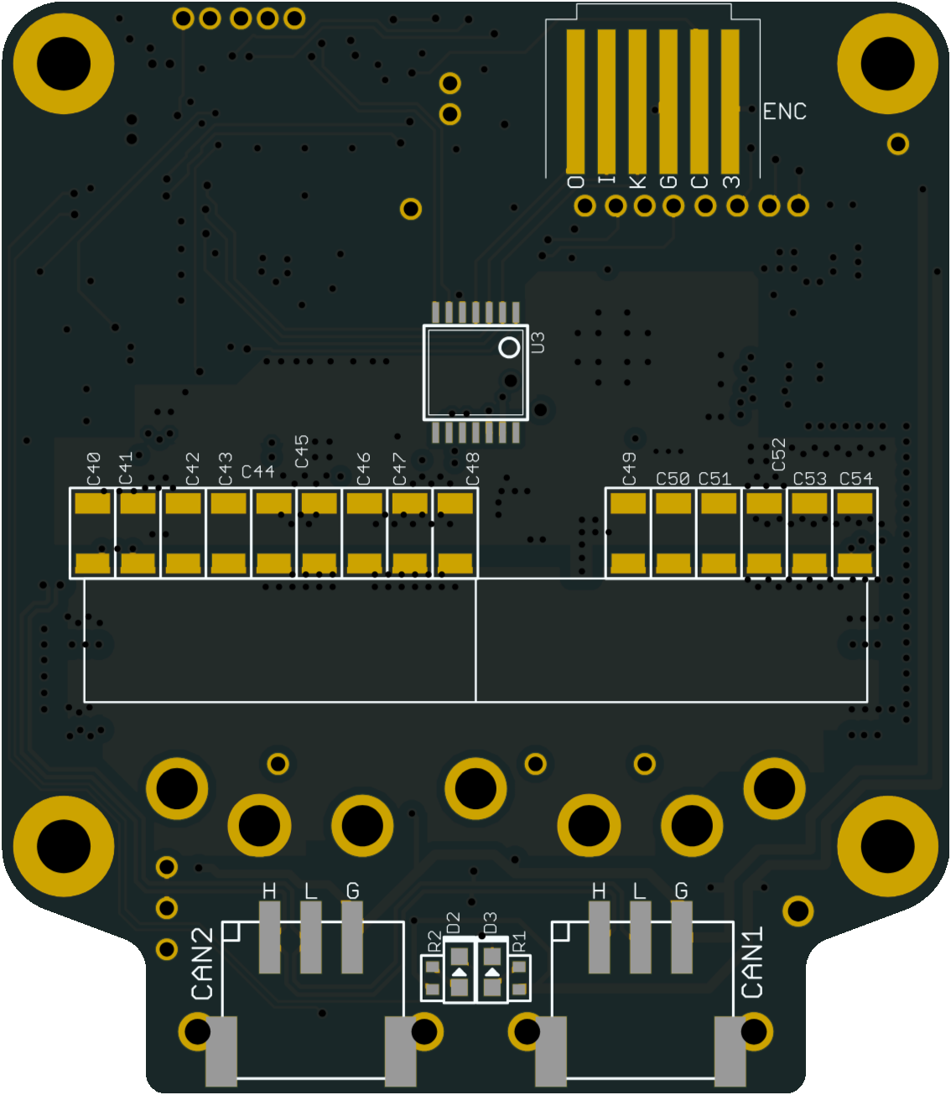
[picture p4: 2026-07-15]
moteus-r4-parent/docs/reference/r4/moteus-r4-back-base.png

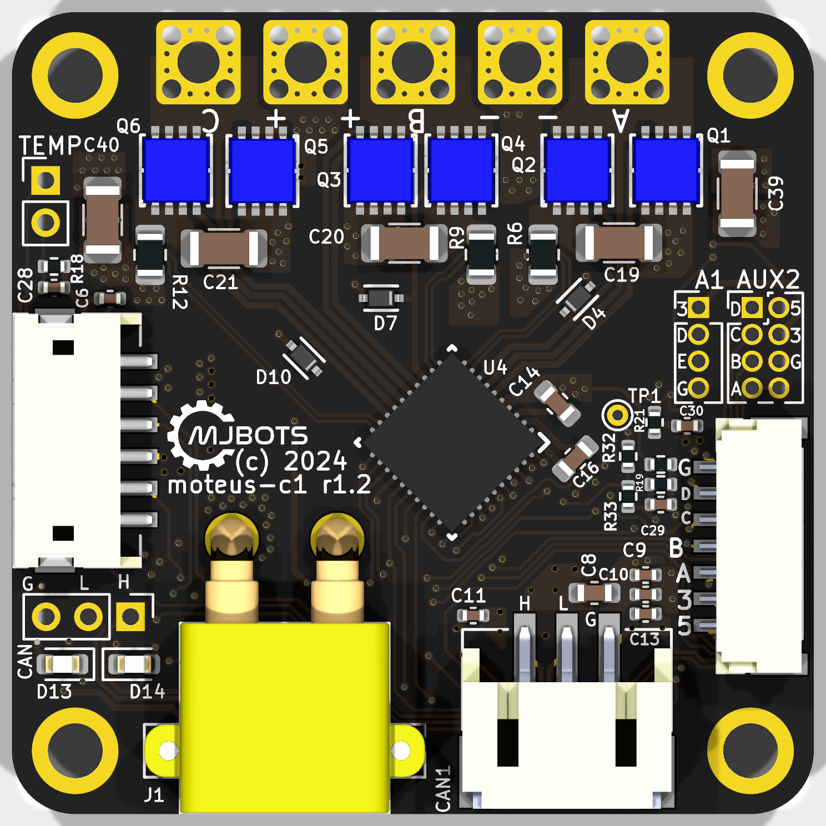
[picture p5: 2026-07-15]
moteus-r4-parent/docs/reference/c1/moteus-c1-base.png

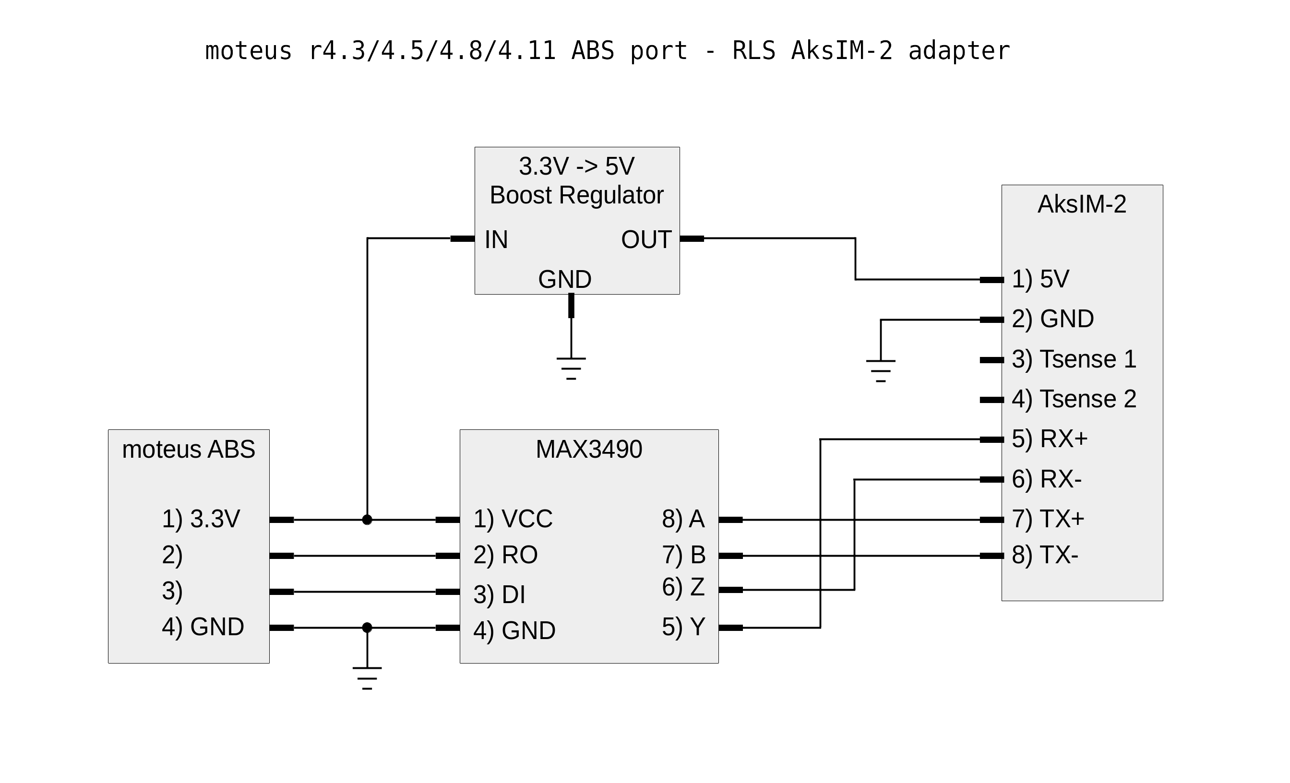
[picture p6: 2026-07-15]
moteus-r4-parent/docs/aksim2_adapter.png

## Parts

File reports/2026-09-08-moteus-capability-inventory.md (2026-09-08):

# What the moteus firmware already gives FlexNode / CATBOT — capability inventory

_2026-09-08. Standing report for Aditya. Baseline: this fork at `5ba2bd8`, upstream firmware ABI
`0x010100` (`fw/moteus_hw.h:209`), register map version 5 (`fw/moteus_controller.cc:47`), board
identity `{family 0, hw_version 8}` (`fw/moteus_hw.cc:37-41`). Companion to
[`docs/can-layer.md`](../docs/can-layer.md) and
[`2026-09-08-can-subsystem-design.md`](2026-09-08-can-subsystem-design.md)._

> **How to read this.** Every claim below is either cited to a source line in `moteus-r4-parent/`
> (paths relative to that directory, `file:line`) or to an upstream doc under
> `moteus-r4-parent/docs/`. Where the firmware has been changed by FlexNode, the FlexNode file is
> cited instead. "Validated" means run on the FlexNode board; almost nothing in the motor path is
> — see the bring-up log. Where behaviour is hedged ("appears to", "the docs say but the code
> does not show") that is deliberate.
>
> **What is validated on FlexNode hardware as of 2026-09-06/07** (`notes/bringup-log.md`): boot,
> main loop, WS2812, IMU over aux2 I²C, standalone power-up. **Not validated:** anything that
> energises the gate driver, the encoder (not soldered), CAN (no adapter), `bus_V` vs DMM, config
> persistence. Everything in §1–§4 about torque production is therefore "what the code does on a
> stock r4.11", not "what we have seen on FlexNode".

---

## 0. The short version

**You get, for free, without writing a line:**

1. A complete FOC servo with fifteen control modes, of which a legged robot uses exactly three
   (position, zero-velocity as the timeout fallback, stopped) and the bench uses two more
   (voltage-FOC for open-loop spin, current for tuning). §1.
2. A position/velocity/feed-forward-torque controller whose command semantics were designed for
   idempotent commands from a high-rate host: `(pos, vel, ff_torque, kp_scale, kd_scale,
   max_torque)` every cycle, with an on-board acceleration-limited trajectory planner that you
   can switch off. §2.
3. Automatic calibration that measures resistance, inductance (d and q), Kv, pole count,
   direction, and a 64-point encoder-to-electrical-angle map, then sets the current-loop
   bandwidth and encoder PLL filter for you. §3.
4. Fault handling for over/under-voltage, FET and motor over-temperature with linear derating,
   gate-driver faults, encoder loss, position/velocity error, plus current, power, velocity and
   position-bound limiting — **in the current-controlled modes only.** §4.
5. Multi-turn absolute output position with a reducer: an output-side I²C encoder (AS5600) can be
   configured as `motor_position.output.reference_source` so the joint angle is known at boot
   without homing. This is the `enc_i2c` channel's primary job, and moteus already does it. §5.4.
6. A 100 ms command watchdog with configurable fallback (damped zero-velocity by default). §2.7.
7. Two aux ports with GPIO in/out, analog in, PWM-in measurement, I²C master (three devices),
   SPI encoders, UART modes including a full register-protocol server over a plain UART. §5.
8. The whole host stack: `moteus_tool`, `tview`, the Python and C++ client libraries, the CAN
   bootloader, a diagnostic tunnel with three streams, and flash-backed configuration. §6.
9. Thirteen telemetry channels readable live with binary schemas. §7.

**Five traps found in the source that will bite CATBOT specifically:**

| Trap | Where | Consequence |
|---|---|---|
| `servo.default_accel_limit` defaults to **50 rev/s²**, and a mode write resets the command to defaults every frame | `fw/bldc_servo_structs.h:594`, `fw/moteus_controller.cc:650`, `fw/bldc_servo_control.h:229-233` | Every gait-rate position command is trajectory-limited unless the corenode sends `accel_limit < 0` each cycle **or** `servo.default_accel_limit` is set to `nan`. Set the config. |
| `servopos.position_min/max` default to **±0.01 rev** | `fw/bldc_servo_structs.h:744-745` | Position mode refuses to start (fault 39) unless the joint is within ±3.6° of zero. Set real limits or `nan` per node. |
| The watchdog only fires in **position** and **stay-within** modes | `fw/bldc_servo_control.h:1670-1674` | A current, voltage-FOC, brake or zero-velocity command with no follow-up runs **forever**. Never leave a node in one of those from a script. |
| `max_current_A`, `max_power_W`, temperature derating, position bounds are enforced **only inside `ISR_DoCurrent`** | `fw/bldc_servo_control.h:817-1124`, §4.2 matrix | Voltage-FOC / PWM / voltage / voltage-DQ / measure-inductance have no current limit at all (only bus-voltage clamps). The bench already learned this. |
| The onboard AS5047 appears to be on **SPI2 = PB13/PB14/PB15**, not SPI1 | `fw/moteus_controller.cc:409-411,518-520`, `fw/aux_mbed.h:604-605`, §5.2 | If true, the "SPI2 expansion pads → TIM1 for the SimpleFOC Mini" plan disconnects the rotor encoder. Netlist check before anything else. |

**The real gaps** are exactly the channel model in `docs/can-layer.md` §3 plus four drivers
(servo pulse, load-cell ADC, ToF, Mini commutation) and the fleet layer. Ranked in §8.

---

## 1. Control modes

### 1.1 The full set

`enum BldcServoMode` (`fw/bldc_servo_structs.h:75-144`); wire names (`:811-829`); register
`0x000` (`docs/protocol/registers.md:77-100`). Column "needs" is what the mode requires before it
will run without faulting; "CATBOT" is whether the running robot ever commands it.

| # | Name | What it does | Needs | Limits enforced | CATBOT |
|---|---|---|---|---|---|
| 0 | `stopped` | Driver disabled after a cooldown (256 cycles of zero-current control then 64 cycles Hi-Z, `fw/bldc_servo_control.h:1434-1449`, config `:658-659`). **Also the only way to clear a fault or leave timeout** (`:1541-1544`). Re-calibrates ADC current offsets on the way out (`fw/bldc_servo.cc:1081-1108`). | — | — | **Yes** — boot state, fault clear |
| 1 | `fault` | Entered on any fault; driver enabled, outputs off. Cannot be commanded. | — | — | observed only |
| 2–4 | `enabling` / `calibrating` / `calib_complete` | Transit states from stopped: DRV8353 enable + CSA offset calibration (`fw/drv8323.cc:77-125`), then 256 ADC samples to find the three current-sense zeros, faulting if any is >200 counts off 2048 (`fw/bldc_servo.cc:1091-1102`). Cannot be commanded. | — | — | transit |
| 5 | `pwm` | Raw duty on the three phases, 0–1 (`:1709-1711`). | nothing | duty clamped to `[min_pwm, max_pwm]` only (`:478-480`) | bench only |
| 6 | `voltage` | Three phase voltages, re-centred on the bus midpoint (`:747-768`). | nothing | duty clamp only | bench only |
| 7 | `voltage_foc` | Sinusoidal voltage at a commanded electrical angle `theta`, advancing at `theta_rate` (`:1424-1432`). **Does not read the encoder and does not check `theta_valid` or `motor.poles`.** | nothing | voltage clamped to `(0.5 - min_pwm) · bus · kSvpwmRatio`; **no current limit** | bench: first spin (already planned, `notes/bringup-log.md` 2026-09-07) |
| 8 | `voltage_dq` | Commanded d/q voltage through the real encoder angle (`:795-815`). | `motor.poles`, `theta_valid` | voltage clamp; **no current limit** | no |
| 9 | `current` | Closed-loop d/q current (`:1725-1729` → `ISR_DoCurrent`). | poles, theta_valid | full chain (§4.2) | tuning only; **no watchdog** |
| 10 | `position` | The main mode: PID on position/velocity → torque → q current, with trajectory planner, feed-forward, limits (§2). | poles, theta_valid, valid output position | full chain + max torque + control-error faults | **Yes — the gait mode** |
| 11 | `pos_timeout` | Entered automatically when the watchdog expires in 10/13; runs `servo.timeout_mode` (`:1451-1476`). Exit only via stop (`:1620-1622`). Can also be commanded directly (`d tmt`). | as per fallback | as per fallback | **automatic** (host-loss floor, can-layer §7 G0) |
| 12 | `zero_vel` | Position controller with `kp_scale = 0`, `ilimit_scale = 0`, velocity target 0, torque capped at `timeout_max_torque_Nm` — a pure damper (`:1137-1154`). | as 10 | full chain, cap 5 Nm default | as the default timeout fallback; **no watchdog when commanded directly** |
| 13 | `within` | Zero torque (feed-forward only) inside `[bounds_min, bounds_max]`; outside, PID back to the violated bound (`:1370-1422`). | as 10 | full chain | maybe — a soft joint limit; see §2.5 |
| 14 | `meas_ind` | Square-wave voltage excitation on d or q to measure inductance (`:1478-1524`). Calibration internal. | theta_valid | voltage clamp only | calibration only |
| 15 | `brake` | All three low-side FETs on; phases shorted (`fw/bldc_servo.cc:1278-1283`). Passive braking, no control. | nothing | none (bus/temperature faults still checked) | candidate knee timeout fallback (design report §9.1); **no watchdog** |

Mode transitions (`ISR_MaybeChangeMode`, `fw/bldc_servo_control.h:1532-1626`): from `stopped`
every active mode first goes through 2→3→4 — the DRV enable takes >1 ms of the 1 kHz poll
(`fw/drv8323.cc:90-99`) and the ADC calibration 256 control cycles (≈8.5 ms at 30 kHz). **First
torque after a stop is therefore roughly 10–15 ms away.** Between active modes the switch is
immediate and clears the PID state (`:1606-1608`). From `fault` or `pos_timeout`, only `stopped` is
accepted; everything else is silently ignored (`:1564-1566`, `:1620-1622`).

### 1.2 What a gait controller actually drives

Only mode 10. The design report's fast lane writes `mode = 10` plus `0x020–0x022` every cycle
(`2026-09-08-can-subsystem-design.md` §4.1), which is also what `moteus.Controller.make_position`
emits (`lib/python/moteus/moteus.py:700-703`). Everything else is either automatic (11, 1, 2–4),
bench (5–9, 14), or a policy choice for the timeout fallback (0/10/12/15,
`fw/bldc_servo_structs.h:615-622`).

Torque-only control is not a separate mode: it is mode 10 with `kp_scale = kd_scale =
ilimit_scale = 0` and a feed-forward torque (`docs/guides/control-modes.md:113-170`). The same
doc's caveat applies to CATBOT: host-side torque control at 350 Hz has ~1/85 the bandwidth of
the on-board 30 kHz loop, so formulate as much of the law as possible as
`position + velocity + feedforward` with scaled gains.

### 1.3 The 30 kHz loop, for orientation

`servo.pwm_rate_hz` defaults to 30 000 for family 0 hw ≥ 3 (`fw/bldc_servo_structs.h:498-502`);
the control interrupt runs at PWM rate up to 30 kHz and at half rate above that
(`fw/bldc_servo_control.h:146-157`). The ISR is split into a top-priority timer half that waits
for the hardware-triggered ADCs, and a PendSV half at priority 6 that does the maths
(`fw/bldc_servo.cc:433-456`, `:758-848`). Encoder SPI reads and aux sampling happen inside that
ISR (`:885-1007`). Anything FlexNode adds to the main loop is pre-empted by it; anything added
to the ISR eats duty-cycle headroom (`:850-883`).

---

## 2. Position mode and the trajectory machinery

### 2.1 The command and its units

`BldcServoCommandData` (`fw/bldc_servo_structs.h:330-433`); registers `0x020–0x02d`
(`fw/moteus_controller.cc:270-283`, `docs/protocol/registers.md:319-465`). All position
quantities are **output-shaft revolutions**, velocities **rev/s**, torques **N·m at the output**
(after `rotor_to_output_ratio`). Integer wire scalings are in `fw/moteus_controller.cc:99-140`
and `docs/protocol/registers.md:9-73`:

| Reg | Field | Unit | int8 / int16 / int32 LSB | Default if not written | Notes |
|---|---|---|---|---|---|
| `0x020` | position | rev | 0.01 / 0.0001 / 0.00001 | 0.0 | NaN (or int min) = "start from where I am" |
| `0x021` | velocity | rev/s | 0.1 / 0.00025 / 0.00001 | 0.0 | the setpoint advances at this rate forever |
| `0x022` | feedforward torque | N·m | 0.5 / 0.01 / 0.001 | 0.0 | added after the PID |
| `0x023` | kp_scale | — | PWM mapping (1/127, 1/32767) | 1.0 | multiplies `servo.pid_position.kp` |
| `0x024` | kd_scale | — | PWM | 1.0 | multiplies kd |
| `0x025` | max torque | N·m | torque | NaN → **100 N·m** in the struct (`:359`); effectively "current limit decides" | see §4 |
| `0x026` | stop position | rev | position | NaN | **deprecated**; fault 45 if combined with limits (`fw/bldc_servo_control.h:286-292`) |
| `0x027` | watchdog timeout | s | 0.01 / 0.001 / 1e-6 | 0 → `servo.default_timeout_s`; NaN → never | §2.7 |
| `0x028` | velocity limit | rev/s | velocity | NaN → `servo.default_velocity_limit`; **negative → no limit** | §2.4 |
| `0x029` | accel limit | rev/s² | 0.05 / 0.001 / 0.00001 | NaN → `servo.default_accel_limit` (**50**); negative → none | §2.4 |
| `0x02a` | fixed voltage override | V | voltage | NaN | open-loop gimbal mode for this command |
| `0x02b` | ilimit_scale | — | PWM | 1.0 | scales the integrator clamp |
| `0x02c` | fixed current override | A | current | NaN | open-loop with a d-axis current |
| `0x02d` | ignore position bounds | bool | int | 0 | disables `servopos` limits for this command |

**Every frame that writes `0x000` resets the whole command struct to these defaults first**
(`fw/moteus_controller.cc:643-653`). That is what makes commands idempotent and stateless, and it
is why a field the corenode does not send each cycle silently reverts.

Fast-lane consequence: the design report uses int16 for position/velocity on the wire. With the
scalings above that is **±3.2767 rev** and **±8.19 rev/s** before saturation (`ScaleSaturate`
clamps to ±max and reserves int min for NaN, `fw/moteus_controller.cc:71-84`). Fine for a joint
that has been zeroed; not fine for a joint whose position was never set — see §2.6.

### 2.2 The PID, in physical units

`PID::Apply` (`fw/pid.h:108-162`) with config `servo.pid_position`
(`docs/reference/configuration.md:30-50`):

```
error       = measured_position - control_position          (rev)      pid.h:132
error_rate  = measured_velocity - control_velocity          (rev/s)    :133
integral   += error · ki · dt, clamped to ±(ilimit · ilimit_scale)     :136-152
p = kp_scale · kp · error ;  d = kd_scale · kd · error_rate            :154-155
command = sign · (p + d + integral)                         (N·m)      :158-159
```

`sign` is −1 by default so positive error (measured ahead of target) gives negative torque
(`fw/bldc_servo_structs.h:679`). Defaults `kp = 4 N·m/rev`, `ki = 1`, `ilimit = 0` (so the
integrator does nothing until `ilimit` is set), `kd = 0.05 N·m/(rev/s)` (`:674-680`). These are
r4.11 defaults for a generic small motor, not a tuned leg; expect to raise kp substantially and
set kd by the plant.

The measured velocity fed to the D term passes through `servo.velocity_threshold`, a deadband on
the velocity *error* (`fw/bldc_servo_control.h:1217-1220`, default 0). Then:

```
unlimited_torque = PID + feedforward_Nm + 2π · control_acceleration · inertia_feedforward   :1226-1237
limited_torque   = clamp(unlimited_torque, ±max_torque_Nm)  → sets limit code 102            :1254-1261
q_A              = torque_to_current(limited_torque · rotor_to_output_ratio) + cogging comp  :1266-1298
```

`torque_to_current` is the inverse of the Kv-derived torque constant with an optional saturation
model (`fw/torque_model.h`, `fw/bldc_servo.cc:313-320`, `fw/bldc_servo_structs.h:459-470`). If
Kv is zero (uncalibrated) the constant falls back to 0.1 N·m/A **and q current is clamped to
±5 A** (`fw/bldc_servo_control.h:176-177`, `:1300-1303`) — a useful built-in guard for the first
closed-loop test.

The docs say kd_scale "is internally limited to be no more than the kp scale"
(`docs/protocol/registers.md:372`); I could not find that clamp in `fw/pid.h` or the callers.
Treat the two scales as independent until proven otherwise.

### 2.3 What the setpoint does between commands

`BldcServoPosition::UpdateCommand` (`fw/bldc_servo_position.h:293-489`) maintains
`control_position` and `control_velocity` and integrates them every ISR cycle in 48-bit
fixed point (`:365-385`; 1 rev = 2⁴⁸ counts, `fw/motor_position.h:427-433`). Three regimes:

1. **No limits (both NaN).** The commanded position becomes `control_position` immediately, the
   commanded velocity becomes `control_velocity`, and the position command is consumed
   (`:322-331`). From then on the setpoint advances at `velocity` each cycle (`:374`). A host
   sending `(x_c, v_c)` at rate f therefore gets a PD around `x = x_c + v_c·t` between frames —
   the "match the trajectory" semantic of `docs/reference/configuration.md:71-74`. **This is what
   a gait controller wants**, with the internal planner off.
2. **Velocity limit only.** Setpoint moves toward the target at ±`velocity_limit` and snaps when
   it would cross (`:66-86`).
3. **Acceleration limit (with or without velocity limit).** A bang-bang planner: accelerate,
   cruise at the velocity limit, decelerate at exactly the rate needed to arrive at the target
   with the target velocity (`CalculateAcceleration`, `:97-181`; `DoVelocityAndAccelLimits`,
   `:183-270`). The target itself keeps advancing at the commanded velocity while the trajectory
   runs (`:387-396`). `trajectory_done` (register `0x00b`) is set when velocity and position are
   both within tolerance (`:246-269`). Once done, the final velocity is held indefinitely
   (`docs/guides/control-modes.md:22-28`).

When position control starts from stopped, `control_position` is captured from the measured
position and `control_velocity` from the filtered measured velocity — treated as exactly zero if
below `servo.velocity_zero_capture_threshold` (0.05 rev/s) — so a moving joint is picked up
without a torque step (`:332-342`). `0x133 RecapturePositionVelocity` does the same on demand
(`fw/bldc_servo.cc:407-417`), intended for use after a period of zero-gain torque control.

The setpoint velocity is always clamped to `motor_max_velocity`, the bus-voltage-derived
achievable speed (`:355-361`, computed in `fw/bldc_servo_control.h:535-624`), so a velocity
command the bus cannot support is trimmed rather than wound up.

### 2.4 Limits and defaults (read this before the first CAN session)

`PrepareCommand` (`fw/bldc_servo_control.h:212-310`) resolves defaults **before** the command
reaches the ISR:

- `timeout_s == 0` → `servo.default_timeout_s` (0.1 s); NaN → never (`:221-223`).
- `velocity_limit` NaN → `servo.default_velocity_limit` (NaN = none); **negative → NaN** (`:224-228`).
- `accel_limit` NaN → `servo.default_accel_limit` = **50 rev/s²** (`fw/bldc_servo_structs.h:594`);
  negative → NaN (`:229-233`).
- If either limit ends up finite, a missing velocity limit is filled with `servo.max_velocity`
  (500 rev/s) and any velocity limit is capped there (`:237-244`).
- The commanded velocity is clamped to ±velocity_limit (`:248-253`).

So with stock config **every position command is acceleration-limited to 50 rev/s²** (≈314
rad/s² at the output). For a joint that is a hard cap on how fast the setpoint can change,
invisible to the host except as tracking lag. For CATBOT either set `servo.default_accel_limit
nan` (and leave `default_velocity_limit nan`) per node, or send `0x029 = -1` every cycle (costs
bytes on the fast lane). Config is the right answer; note it in the bring-up config list.

`servo.max_position_slip` / `servo.max_velocity_slip` (`fw/bldc_servo_position.h:398-427`,
`docs/reference/configuration.md:144-158`) bound how far the setpoint may run ahead of the
measured state — the standard fix for "catch-up" lunges in velocity mode. Both NaN by default.

### 2.5 Position bounds and `stay_within`

`servopos.position_min/max` (`fw/bldc_servo_structs.h:743-752`) act three ways:

1. Starting position or stay-within mode outside them faults with 39 `kStartOutsideLimit`
   (`fw/bldc_servo_control.h:1594-1598`); bounds beyond ±32768 rev fault with 48 (`:1599-1604`).
2. The **setpoint** is saturated at the bounds every cycle, and hitting one zeroes the control
   velocity (`fw/bldc_servo_position.h:429-448`, `:474-479`).
3. Inside `ISR_DoCurrent`, q current that pushes further past a bound is derated linearly to
   zero over `servo.position_derate` (0.02 rev) beyond it, with limit code 103 (`:831-859`).

The defaults are **±0.01 rev**. They must be set per joint (a real range, or `nan` to disable)
before position mode will even start. `0x02d ignore_position_bounds` bypasses all three for one
command (`fw/bldc_servo_position.h:443`, `fw/bldc_servo_control.h:833`).

`stay_within` (13) is a softer tool: bounds are per-command (`0x040/0x041`), zero PID torque
inside, feed-forward still applied, PID to the violated bound outside
(`fw/bldc_servo_control.h:1370-1422`). It shares the watchdog with position mode. For CATBOT it
is a possible "compliant leg with hard stops" primitive during stand-up or fall; the gait itself
would not use it.

### 2.6 Position representation, wrap, homing, rezero

- Internal position is 64-bit fixed point (48 bits per revolution); float I/O is limited to
  ±32768 rev (`docs/reference/limits.md:3-26`; `ISR_InvalidLimits`). Wrap-around is safe when the
  position command is NaN or kp is zero (velocity control) — otherwise a wrap is a large error.
- Three "homed" states (`fw/motor_position.h:325-335`, register `0x00c`,
  `docs/protocol/registers.md:164-172`): `relative` (nothing known), `rotor` (referenced to the
  absolute rotor encoder — the state after boot with the AS5047), `output` (referenced to the
  output).
- **With a reducer the output position is ambiguous at boot.** The AS5047 gives the rotor angle;
  moteus latches the output position on the first sample as the rotor angle scaled by
  `rotor_to_output_ratio`, wrapped to ±½ of one rotor turn's worth of output travel
  (`fw/motor_position.h:924-938`, `output_ambiguity_scale_` `:769-772`). For an 8:1 hip that is
  ±1/16 rev; for a 14:1 knee ±1/28 rev. The host then has to disambiguate.
- Disambiguation tools, all stock:
  - `0x130 SetOutputNearest` — pick the whole number of rotor turns that puts the output nearest
    the given value (`fw/motor_position.h:458-470`, `:1465-1547`). Python `set_output_nearest`.
    This is what `moteus_tool --zero-offset` uses after storing an offset (`moteus_tool.py:1250-1263`).
  - `0x131 SetOutputExact` — force the output position (`:421-425`).
  - `0x132 RequireReindex` — back to `relative`, forces re-homing (`:472-478`).
  - `d cfg-set-output <pos>` — adjust `motor_position.output.offset` so the current reading equals
    `pos` (not persisted until `conf write`; `docs/protocol/diagnostic.md:159-167`).
  - **`motor_position.output.reference_source`** — a second, output-side absolute source
    (I²C AS5600 on the joint, `reference = output`) used at power-on to resolve the ambiguity
    automatically (`fw/motor_position.h:968-983`, `:1477-1530`;
    `docs/reference/encoders.md:316-319`). Homed goes straight to `output` with no host action.
    See §5.4 — this is the single most valuable thing the aux subsystem already does for a legged
    robot.
- `motor_position.output.offset` / `.sign` set the zero and direction at the output
  (`fw/motor_position.h:157-181`).

### 2.7 The watchdog, precisely

- Every accepted position/stay-within command carries `timeout_s` (resolved as in §2.4). The ISR
  latches a nonzero or NaN value into `status.timeout_s` once and then decrements it each cycle
  (`fw/bldc_servo.cc:890-894`, `fw/bldc_servo_control.h:1635-1638`).
- When it reaches zero **and the mode is 10 or 13**, mode becomes 11 (`:1670-1674`). Any other
  active mode is not watched.
- Mode 11 runs `servo.timeout_mode`: 0 stop, 10 decelerate-and-hold using the default
  velocity/accel limits and default gains, 12 zero-velocity damping capped at
  `timeout_max_torque_Nm` (default 5 N·m), 15 brake (`:1451-1476`;
  `docs/reference/configuration.md:301-314`). Anything else falls back to stop (`:1473-1475`).
- The **only exit is a stop command**, then re-arm (`:1620-1622`;
  `docs/troubleshooting/timeout-mode-11.md:14`). A corenode that comes back must send mode 0 then
  mode 10; it cannot just resume sending position frames. The design report's "the next valid
  command frame re-arms the axis" (§9.1) is **wrong as written** — it needs a stop first. The
  Python `set_position_wait_complete` helper treats mode 11 as a fault for the same reason
  (`moteus.py:787-788`).
- Diagnostic-channel commands (`d pos …`) default to no timeout unless `t` is given
  (`docs/troubleshooting/timeout-mode-11.md:16`), which is why tview sessions never time out and
  scripts do.

The design report's recommendation of 30 ms and mode 12 with a tuned `timeout_max_torque_Nm`
stands; add "stop-then-re-arm" to the corenode's recovery path.

---

## 3. Calibration and startup

### 3.1 What `moteus_tool --calibrate` does

`do_checked_calibrate` (`lib/python/moteus/moteus_tool.py:1497-1714`). Preconditions: commutation
source must be slot 0 (`:1513-1516`); the motor must spin freely; the host has the diagnostic
tunnel (CAN or the UART `kSerial` path — §6.6).

| Step | What happens | What it writes |
|---|---|---|
| 0 | Clears all 64 `motor.offset.N`, sends `d stop`, sets `motor.phase_invert 0` and `motor_position.sources.0.sign 1` (`:1524-1564`) | those |
| 1 | Winding resistance by stepping voltage-FOC and measuring current (`calibrate_winding_resistance2`) | `motor.resistance_ohm` |
| 2 | Inductance via `meas_ind` mode (`calibrate_inductance`) | `motor.inductance_d_H`, then d/q separately (`calibrate_dq_inductance`, `:1614-1617`) |
| 3 | Current-loop bandwidth from R and L (`calculate_bandwidth`; default `--cal-bw-hz`) | `servo.pid_dq_hz` (`:1593-1595`) — the firmware derives the PI gains itself (`fw/bldc_servo_control.h:392-397`) |
| 4 | Encoder PLL filter bandwidth (`set_encoder_filter`) | `motor_position.sources.0.pll_filter_hz` |
| 5 | **Encoder-to-phase map**: spins one full encoder revolution each way in voltage-FOC (or current mode on newer firmware if the current-sense quality is good, `:1886-1924`), records (commanded electrical angle, encoder count), fits pole count, direction and a 64-bin offset table (`calibrate_encoder.py` via `ce.calibrate`, `:1948-1961`) | `motor.poles`, `motor_position.sources.0.sign`, `motor.phase_invert`, `motor.offset.0..63` (`:1972-1985`) |
| 6 | Kv by spinning at known voltage and measuring speed (`calibrate_kv_rating`) | `motor.Kv` → torque constant (`fw/bldc_servo.cc:313-320`) |
| 7 | Optional Ld saturation (`--cal-measure-ld-saturation`) | `motor.inductance_d_scale` |
| 8 | `d rezero`, decides `servo.voltage_mode_control` from current-sense quality (`:1638-1659`) | that flag |
| 9 | `conf write` unless `--cal-no-update`; writes a JSON report to the moteus log directory (`:1664-1714`) | flash |

Options that matter for CATBOT motors (`docs/guides/calibration.md`): `--cal-motor-power` (default
7.5 W; the GIM8108 at 0.22 Ω line-to-neutral needs checking), `--cal-force-kv` to avoid the
high-speed run on a geared joint, `--cal-bw-hz` for torque bandwidth, `--cal-invert` to choose
the positive direction, `--cal-hall` is irrelevant. The **phase-order gate** in
`docs/firmware.md` is precisely step 5: on a current-limited supply, a converging fit with a
pole count that matches the datasheet (many 8108-class outrunners are 21 pole pairs = 42; verify
for the GIM8108-8 and the 5010 before trusting the fit) is the proof that logical phases and
sensed phases pair correctly.

### 3.2 Encoder-to-rotor alignment at runtime

`electrical_theta = wrap(ratio · poles/2 · 2π / rotor_scale + lerp(motor.offset, ratio))` where
`ratio = filtered_encoder / cpr` (`fw/motor_position.h:849-862`). The 64-entry table is linearly
interpolated around the circle; a jump >3.5 rad between neighbours (an old per-bin-wrapped table)
is refused with `discontinuous_offset` (`:544-556`). The commutation source may reference the
output rather than the rotor only for integral reductions ≤1 (`:693-717`); CATBOT keeps the
AS5047 on the rotor, which is always fine.

### 3.3 What must be re-run when

| Change | Re-run |
|---|---|
| New motor, or same motor re-mounted on the encoder magnet, or magnet moved | full `--calibrate` (`docs/guides/calibration.md:3-10`) |
| Different reducer ratio | only `motor_position.rotor_to_output_ratio` (config; also read by calibration for Kv scaling, `moteus_tool.py:1536-1540`) |
| Joint re-zeroed mechanically | `--zero-offset` / `--set-offset` (`:1250-1263`), or `d cfg-set-output` + `conf write` |
| Firmware upgrade across an ABI change | nothing manual — `moteus_tool --flash` captures `conf enumerate`, migrates it through `FirmwareUpgrade.fix_config`, and restores (`:1356-1383`) |
| Board swap onto an existing joint | full calibration (the offset table is per encoder/magnet pair) |

### 3.4 What happens on a board with no encoder

- `motor_position.sources.0` defaults to the onboard SPI (`fw/motor_position.h:192-198`). With no
  AS5047 the SPI reads never become active, so `theta_valid` and `position_relative_valid` stay
  false.
- Modes 8, 9, 10, 12, 13 fault immediately: 42 `theta_invalid` or 43 `position_invalid`
  (`fw/bldc_servo_control.h:802-806`, `:825-829`, `:1205-1215`); with `motor.poles = 0`, 36
  `motor_not_configured` first.
- Modes 5, 6, 7, 15 work — which is why the open-loop bench image uses 7.
- `servo.fixed_voltage_mode` (or the per-command `0x02a/0x02c` overrides) makes mode 10 run
  open-loop like a gimbal driver: the electrical angle is synthesised from the control position
  and pole count, the encoder is ignored, reported position equals the setpoint
  (`fw/bldc_servo_control.h:303-307`, `:500-507`, `:1178-1203`;
  `docs/reference/configuration.md:115-137`). **All current limits and derating are bypassed in
  that path** (only the over-temperature fault survives). Useful once for a no-encoder motion
  test, dangerous as anything else.
- Every boot also performs the DRV8353 CSA offset calibration and the 256-sample ADC zero
  (§1.1 rows 2–4) — that is not the same as `--calibrate` and needs no encoder.
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

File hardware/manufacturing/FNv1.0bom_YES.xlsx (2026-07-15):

Name | Description | Designator | Footprint | LibRef | Quantity | LCSC # | LCSC alt #
PAD16AWG_PAD |  | A, B, C | 16AWG_PAD | PAD16AWG_PAD | 3
0402B104K500CT | CAP CER 0.1UF 50V X7R 0402 | C1, C5, C6, C8, C12, C14, C17, C22, C27, C28, C61, C63 | FP-0402B104K500CT-IPC_C | CMP-45632-000010-1 | 12 | C152814
CC1206KKX5R9BB106 | CAP CER 10UF 50V X5R 1206 | C2, C18, C19, C20, C29, C30, C31, C32, C33, C34, C35, C36, C37, C38, C39, C40, C41, C42, C55, C56 | FP-CC1206-FD-MFG | CMP-03422-001420-1 | 20 | C5449000
C0402C104M3PAC7867 | CAP CER 0.1UF 25V X5R 0402 | C3 | FP-C0402-BB-MFG | CMP-03020-014070-2 | 1 | C152814
04026D475MAT2A |  | C4 | CAPC1005X56X25NL10T15 | CMP-2008-02754-1 | 1 | C368809
0402YD105MAT2A | General Purpose Ceramic Capacitor, 0402, 1uF, 20%, X5R, 15%, 16V | C7, C13, C16, C23, C24 | FP-0402-L_1_0_1-W_0_5_0_1-IPC_C | CMP-04427-002736-1 | 5 | C1518208
AC0402KRX7R8BB102 | CAP CER 1000PF 25V X7R 0402 | C9, C10, C11 | FP-AC0402-0_5-IPC_C | CMP-03422-001379-1 | 3 | C14442
CC0402KRX7R6BB474 | CAP CER 0.47UF 10V X7R 0402 | C15 | FP-CC0402-MFG | CMP-03422-000442-1 | 1 | C106255
CC0402KRX5R7BB225 | CAP CER 2.2UF 16V X5R 0402 | C21 | FP-CC0402-CC-MFG | CMP-03422-000732-3 | 1 | C723363
UMK105CBJ105KV-F | None | C25, C26, C57 | FP-0402-L_1_0_0_2-W_0_5_0-MFG | CMP-14477-002788-2 | 3 | C1518208
DNP | Library: MF_Passives Description: Device for Non-Polarized Capacitors. Manufacture part number (MPN) can be added via Attributes. Check https://factory.macrofab.com/parts for the house parts list. | C43, C44, C45, C46, C47, C48, C49, C50, C51, C52, C53, C54 | C1206_NOCREAM | CAPACITOR_NP_1206_NOCREAM | 12
C1206C104J2RACTU | CAP CER 0.1UF 200V X7R 1206 | C58, C60 | FP-C1206C-EB-MFG | CMP-1037-04220-3 | 2 | C697702
C0603C104M5RAC7411 | C0603 0.10 μF X7R 30ppm/°C 20.00% 50 V | C59 | FP-C0603C-CF-IPC_C | CMP-03020-022979-2 | 1 | C15725
C0402C103K3RALTU |  | C62 | CAPC1005X60X30LL05T10 | CMP-2008-02101-1 | 1 | C60133
CC1206KKX7R9BB474 | CAP CER 0.47UF 50V X7R 1206 | C64 | FP-CC1206-F1-MFG | CMP-03422-000324-2 | 1 | C277483
WS2812B2020 | LED; SMD; 2020; RGB; 2x2x0.84mm; 3.7Ã·5.3V; Lens: transparent; 2kHz | D1 | LED_WS2812B2020 | CMP-004-00031-1 | 1 | C52917434
SZNUP2105LT3G | Dual Line CAN Bus Protector, 3-Pin SOT-23, Pb-Free, Tape and Reel | D2 | ONSC-SOT-23-3-318-08_V | CMP-1063-00169-1 | 1 | C719799
SM0402GC | LED GREEN CLEAR 0402 SMD | D3 | FP-SM0402GC-MFG | CMP-35283-000001-2 | 1
BAT41KFILM | DIODE SCHOTTKY 100V 200MA SOD523 | D4, D5, D6, D7, D8, D9, D10, D11, D12 | FP-SOD-523-MFG | CMP-12187-000015-1 | 9 | C73150
STM32G474_CEU6 | ARMÂ® CortexÂ®-M4F STM32G4 Microcontroller IC 32-Bit Single-Core 170MHz 512KB (512K x 8) FLASH 48-UFQFPN (7x7) flexnode core | IC1 | QFN50P700X700X60-49N | CMP-031-00008-3 | 1 | C1342773 | C5270382
Legend-Si LGS5160C | 65V, 3A Wide Output Range, Low Ripple, Synchronous Buck Converter | IC*1 | SOP127P600X170_HS-9N | CMP-019-00053-1 | 1 | C5369107
DRV8353SRTAT | IC MTR DRVR DC 6-95V 40WQFN | IC*2 | FP-RTA0040B-IPC_C | CMP-04915-000051-1 | 1 | C2150480
S3B-PH-K-S(LF)(SN) | CONN HEADER R/A 3POS 2MM | J1, J3, J4 | FP-S3B-PH-K-S_LF_SN-MFG | CMP-17439-000039-1 | 3
S4B-PH-K-S(LF)(SN) | Connector Header Through Hole, Right Angle 4 position 0.079 (2.00mm) | J2 | JST_S4B-PH-K-S(LF)(SN) | CMP-002-00074-1 | 1
IHLP1616BZER2R2MA1 | Fixed Inductors Automotive High Saturation Series SMT 2.2uH 2.85A 90mΩ 20% | L1 | FP-IHLP-1616BZ-FP_1_8545x-MFG | CMP-02424-000512-1 | 1 | C49009284
ACT1210D-101-2P-TL00 | Description | L2 | IND_01-2P-TL00_TDK | CMP-006-00025-2 | 1 | C51949467
TSW-105-05-G-S | 0.025" SQ Post Header, Through-hole, Vertical, -55 to 125 degC, 2.54 mm Pitch, 5-Pin, Male, RoHS | P1 | SMTC-TSW-105-05-X-S | CMP-1024-00363-1 | 1
BSC016N06NSATMA1 | MOSFET N-CH 60V 30A TDSON-8 | Q1, Q2, Q3, Q4, Q5, Q6 | FP-PG-TDSON-8-MFG | CMP-32901-000166-1 | 6 | C55106738
CRCW040250K0FKED | RES Thick Film, 50kΩ, 1%, 0.063W, 100ppm/°C, 0402 | R1, R2, R3, R4 | FP-CRCW0402-e3-IPC_A | CMP-02407-005152-1 | 4 | C166559
AC0402DR-071KL | RES 1kΩ ±0.5% 0.063W 0402 | R5 | FP-AC0402-IPC_A | CMP-03412-044280-1 | 1 | C2909307
CRCW040222R0FKEE | RES Thick Film, 22Ω, 1%, 0.063W, 100ppm/°C, 0402 | R6, R7, R8 | FP-CRCW0402-e3-IPC_C | CMP-02407-004337-1 | 3 | C427230
2K 1% 0402(1005) | 2K 0.063W 1% 0402 (1005 Metric) SMD | R9, R10, R22, R26 | RESC0402(1005)_L | CMP-1011-00542-1 | 4 | C2909344
WSL12065L000FEA |  | R11 | RESC3216X89X64NL25T25 | CMP-2003-04336-1 | 1 | C46961736
AC0402FR-7W10KL | RES 10kΩ ±1% 0.125W 0402 | R12, R14, R28, R31 | FP-AC0402-IPC_C | CMP-03412-044365-1 | 4 | C2906861
AC0402FR-7W200KL | RES 200kΩ ±1% 0.125W 0402 | R13 | FP-AC0402-IPC_B | CMP-03412-042654-1 | 1 | C114763
AC0402FR-7W1ML | RES 1MΩ ±1% 0.125W 0402 | R15 | FP-AC0402-MFG | CMP-03412-040456-1 | 1 | C138033
CRGP0402F100K | SMD Precision Pulse Thick Film Chip Resistor | R16, R29 | FP-CRGP0402-IPC_C | CMP-03211-001392-1 | 2 | C60491
AF0402FR-07249KL | Anti-Sulfurated Chip Resistors Automotive Grade 249kΩ 1% 100ppm/°C 0402 | R17 | FP-AF0402-IPC_C | CMP-03412-045933-1 | 1 | VERIFY: RC0402FR-07249KL (249k 1% 0402)
CR0402-FX-1200GLF | Thick Film Chip Resistors 0402 120Ω 0.0625W 1% 100ppm/°C | R18 | FP-CR0402-IPC_C | CMP-2002-04740-2 | 1 | C2909315
AC0402FR-077R5L | RES 7.5Ω ±1% 0.063W 0402 | R19, R20, R21, R23, R24, R25 | FP-AC0402-IPC_C | CMP-03412-035159-2 | 6 | C723369
NCU15WB473FB6RC | NCU15WB473FB6RC Thermistor Ntc 47K 4050K 0402 | R27 | FP-NCP15-NCU15-0_05-MFG | CMP-00260-134754317-1 | 1 | C2991842
MCS0402MC4701FE000 | RES SMD 1.2K OHM 1% 1/10W 0402 | R30 | FP-MCS0402-IPC_C | CMP-02407-008912-1 | 1 | C138040
CRMA1206AF500KFKEF | CRMA1206AF500KFKEF Res Thick Film 1206 500K Ohm 1% 0.3W ±100ppm/C Pad SMD Automotive T/R | RA1, RB1, RC1 | FP-CRMA1206-IPC_C | CMP-00030-87449095-1 | 3 | C18724160
SHORTT5 | Short between two nets | SH1, SH2, SH3 | SHORT_TOP-50 | SHORTT5 | 3
SHORTMEDIUM | Short between two nets | SH4 | SHORT_TOP-MEDIUM | SHORTMEDIUM | 1
VL53L7CXV0GC1 | Time-of-Flight (ToF) 8x8 multizone ranging sensor with 90 degrees FoV | U1 | LGA16_OPTICAL-LINER_STM | CMP-041-000000-3 | 1
LSM6DS3TR | IMU ACCEL/GYRO I2C/SPI 14VFLGA | U2 | FP-LGA-14-DM00249496-MFG | CMP-2000-05193-2 | 1 | C967633
AS5047P-ATSM | Rotary Encoder Magnetic Programmable PWM - | U3 | SOP65P640X120-14N | CMP-034-000000-1 | 1
TCAN334GDCNT | IC TRANSCEIVER 1/1 SOT23-8 | U4 | FP-DCN0008A-IPC_C | CMP-04872-000168-1 | 1 | C2671013
MCP1700T-3302E/TT | Low Quiescent Current LDO, 3-Pin SOT-23, Extended Temperature, Tape and Reel | U5 | SOT-23-TT3_N | CMP-0136-00791-1 | 1 | C7434186

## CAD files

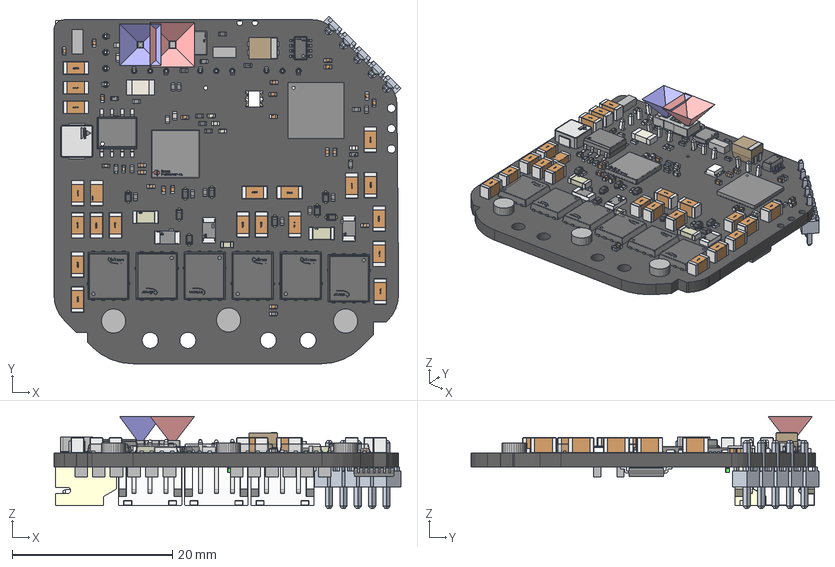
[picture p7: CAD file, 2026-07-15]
CAD/FlexNode.step
43.3 x 43.4 x 11.5 mm
side x 64
Yageo Logo x 20
terminals x 15
top x 28
value x 3
name x 2
logo x 26
Yageo
terminal x 13
pins
Leader x 8
Extruded x 58
Vishay x 7
STM Logo
Bourns
JST x 3
Cap_Yageo_AC0402KRX7R7BB471_eec x 12
STMicroelectronics BAT41KFILM 2 x 9
STMicroelectronics BAT41KFILM 1 x 9
Walsin x 12
Cap_KEMET_C1206C472K4RACTU_eec x 6
Cap_KEMET_C0603C272M5JACTU_eec x 3
VL53L7_SUBSTRATE_Customer Model
VL53L7 CAP_Customer Model
VL53L7_Tx Exclusion Cone_Tx Exclusion Cone
VL53L7_Rx Exclusion Cone_Rx Exclusion Zone
FRAME
Texas Logo Yury - Copy
Texas Logo Yury
TSW-105-05-X-S
Body001 (Mirror #1) x 7
XY-plane x 12
X-axis x 12
Cap_Yageo_CC1206KKX7R9BB474_eec x 4
IC_BODY
IC_LEG x 4
circle
Texas Instruments
IC_LEG_MIR3 x 4
Murata Logo 3
Infineon Logo x 6

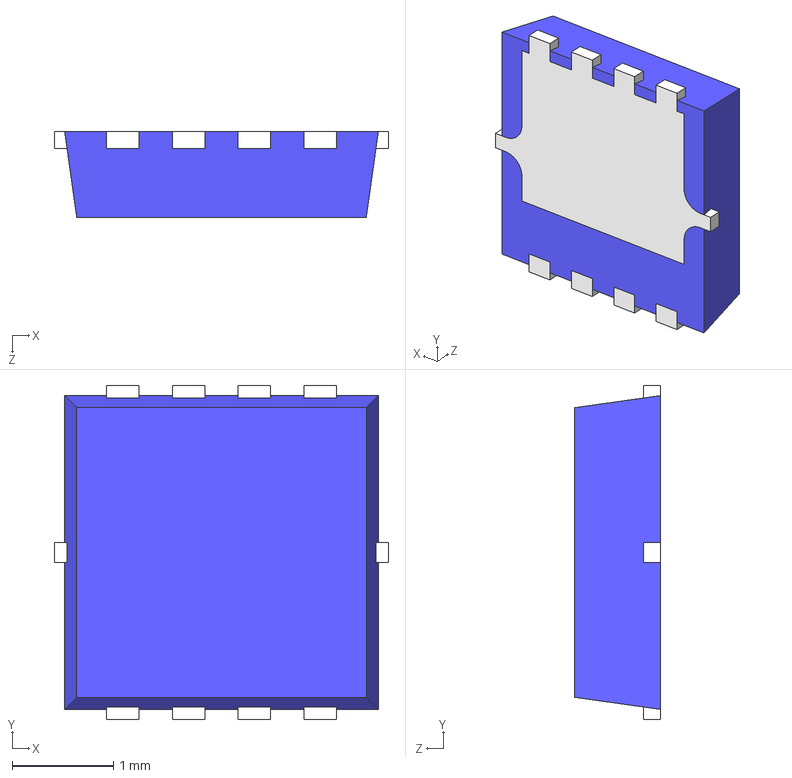
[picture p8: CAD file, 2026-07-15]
moteus-r4-parent/hw/c1/3d/TSON Advance.step
3.30 x 3.30 x 0.85 mm

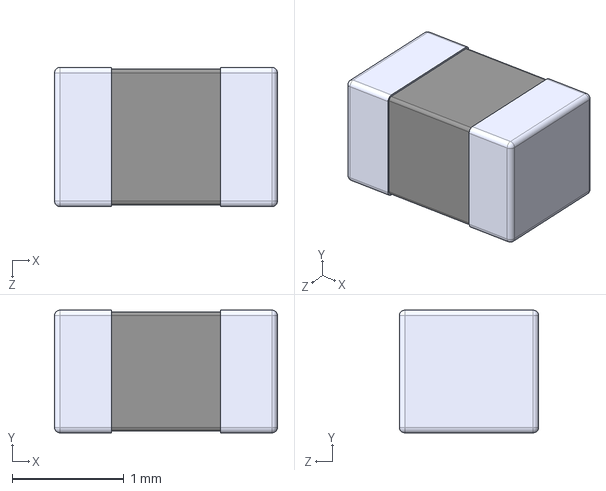
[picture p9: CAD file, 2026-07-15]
moteus-r4-parent/hw/mjuart/3d/MI0805K400R-10.step
2.00 x 1.10 x 1.25 mm

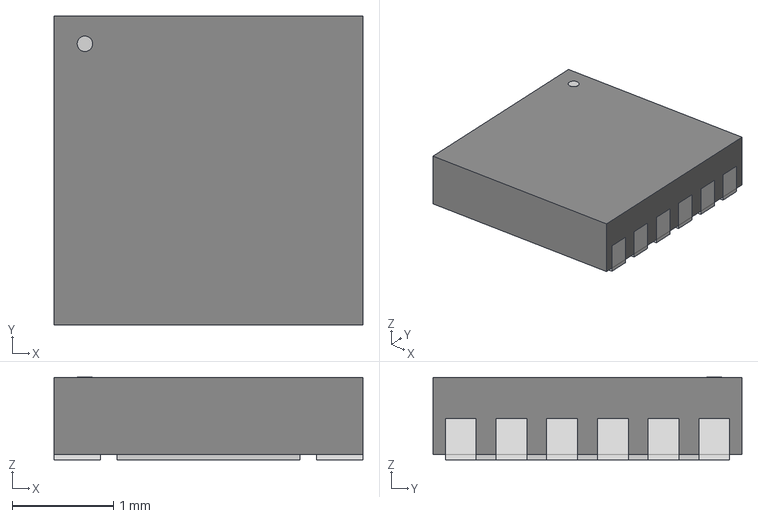
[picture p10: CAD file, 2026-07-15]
moteus-r4-parent/hw/x1/3d/21-0664E_1233-1C_MXM.step
3.05 x 3.05 x 0.815 mm

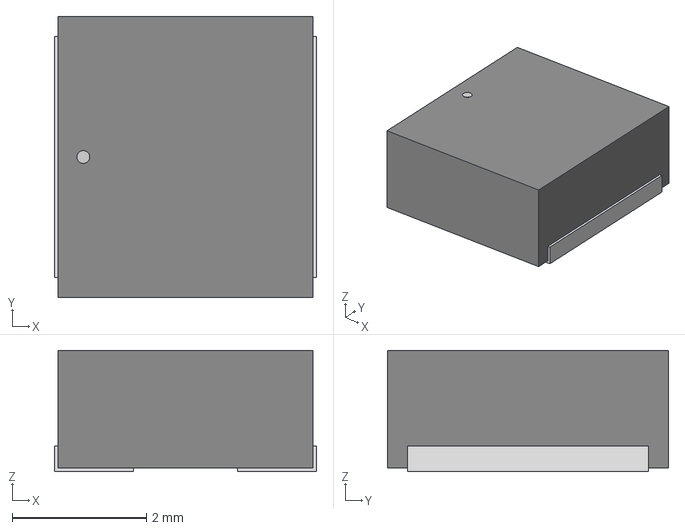
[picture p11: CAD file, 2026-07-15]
moteus-r4-parent/hw/c1/3d/IND_4018-WE-LQS_WRE.step
3.91 x 4.19 x 1.81 mm

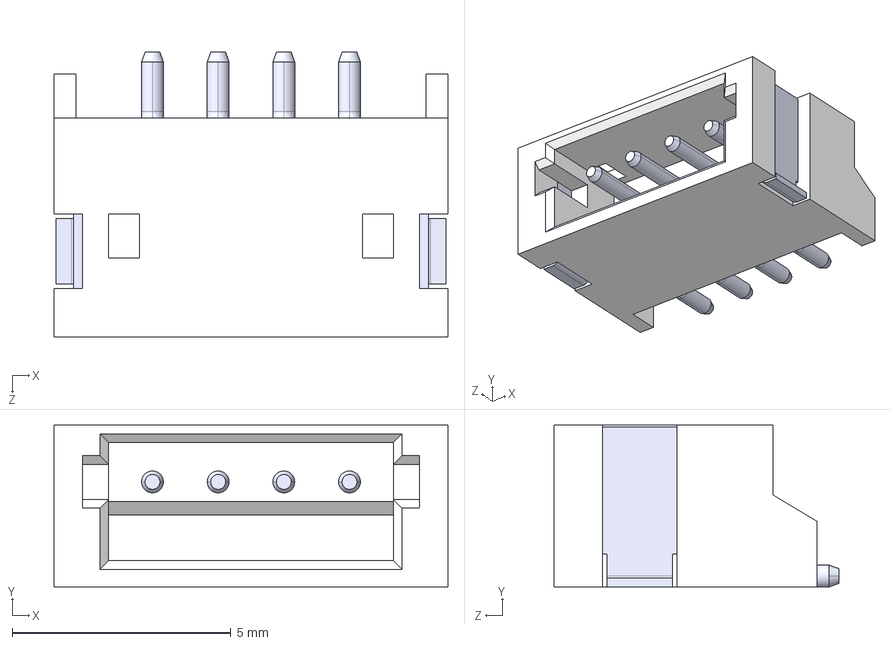
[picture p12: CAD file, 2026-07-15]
moteus-r4-parent/hw/mjuart/3d/S4B-ZR-SM4A-TF.STEP
9.00 x 3.70 x 6.50 mm

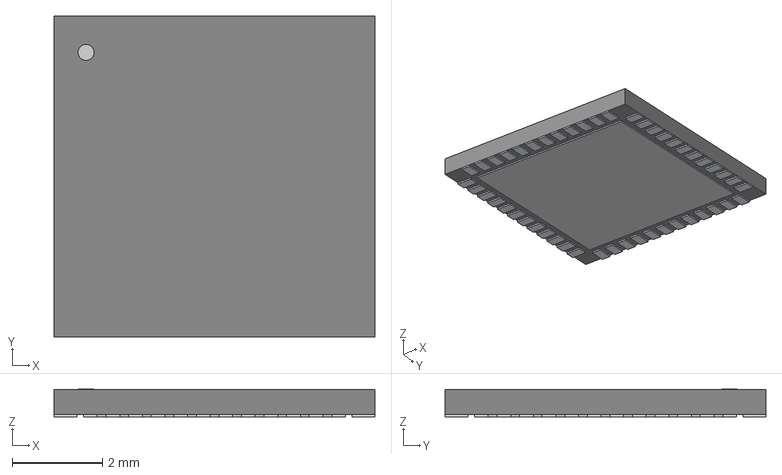
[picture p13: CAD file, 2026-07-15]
moteus-r4-parent/hw/x1/3d/UFQFPN-48_7X7X0P55MM.step
7.11 x 7.11 x 0.612 mm

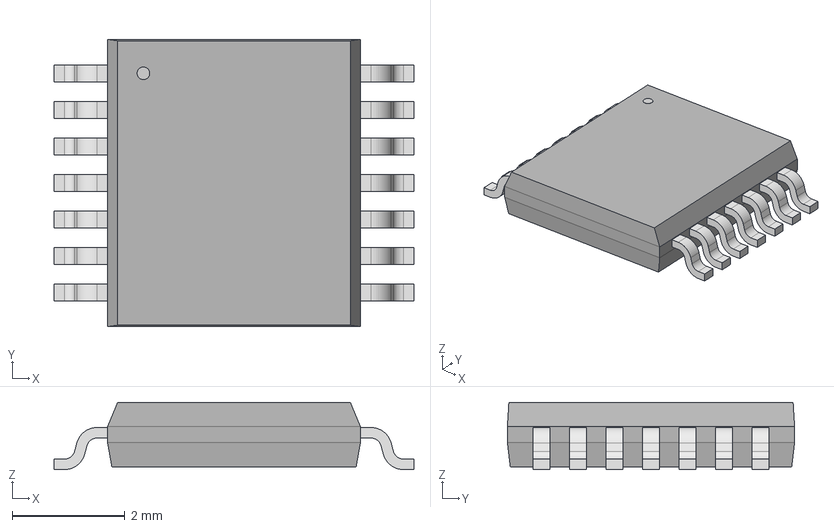
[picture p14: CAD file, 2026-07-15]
moteus-r4-parent/hw/c1/3d/TSSOP14_OSM.step
6.40 x 5.11 x 1.20 mm

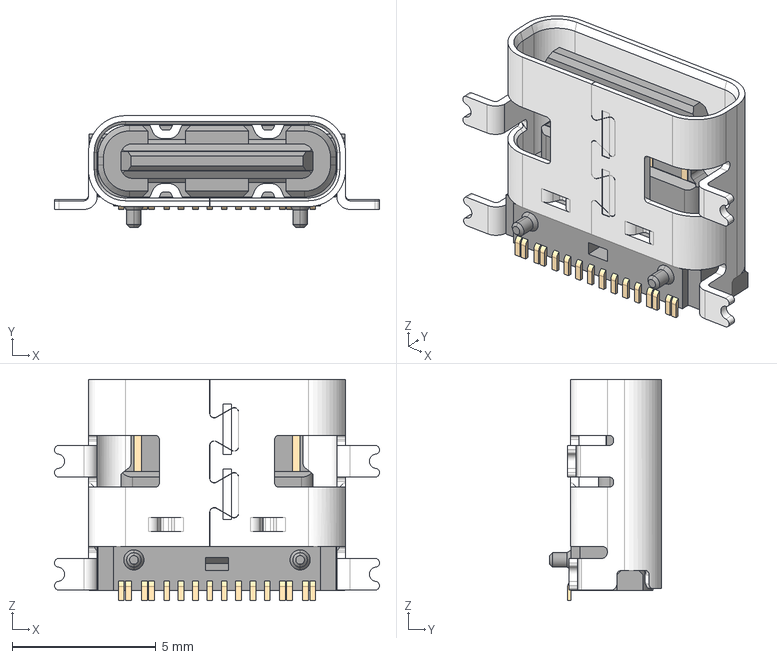
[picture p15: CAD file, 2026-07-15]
moteus-r4-parent/hw/mjuart/3d/usb4110-gf-a.stp
11.3 x 3.89 x 7.70 mm

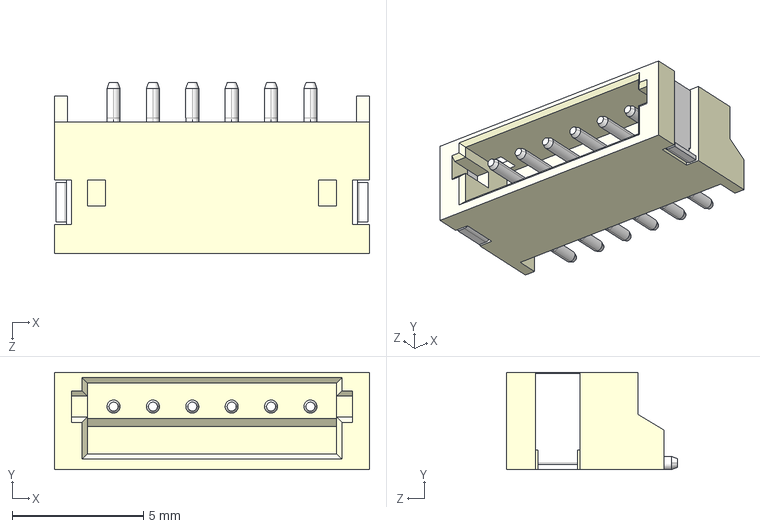
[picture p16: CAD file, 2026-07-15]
moteus-r4-parent/hw/c1/3d/S6B-ZR-SM4A-TF_LF__SN_.step
12.0 x 3.70 x 6.50 mm

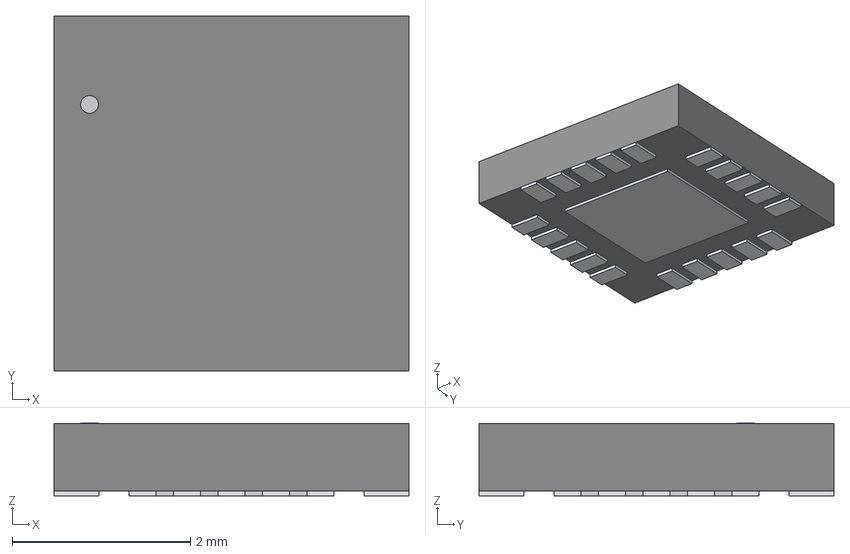
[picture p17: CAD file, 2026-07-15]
moteus-r4-parent/hw/mjuart/3d/QFN20_FT231XQ_FTD.step
3.99 x 3.99 x 0.815 mm

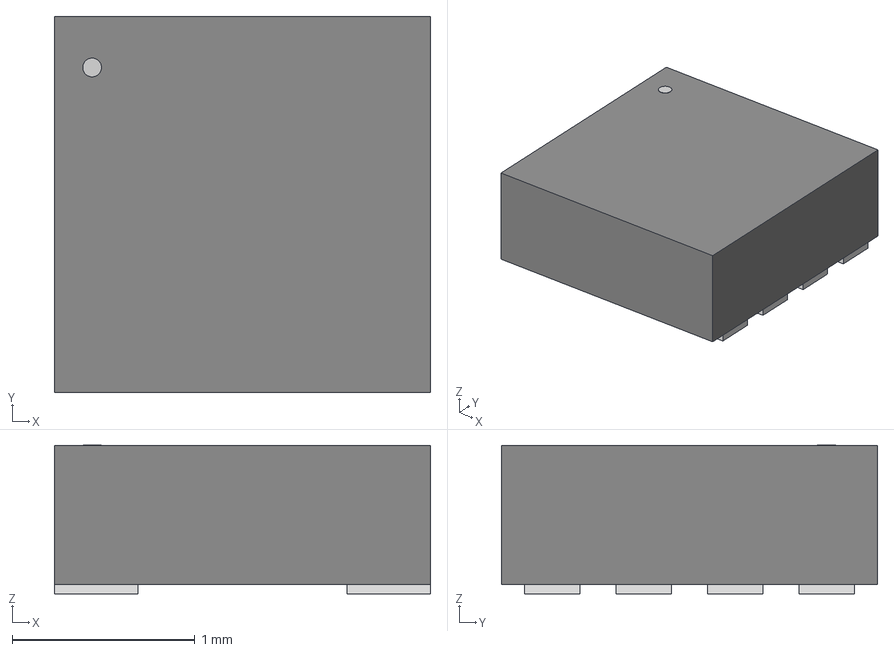
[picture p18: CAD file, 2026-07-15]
moteus-r4-parent/hw/x1/3d/21-0487A_MXM.step
2.06 x 2.06 x 0.815 mm

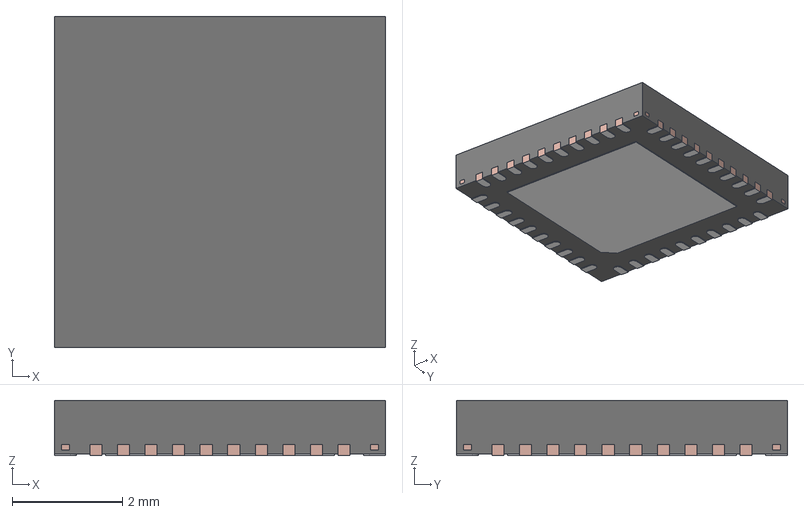
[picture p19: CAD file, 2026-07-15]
moteus-r4-parent/hw/c1/3d/RTA0040B.stp
6.00 x 6.00 x 1.00 mm
FRAME

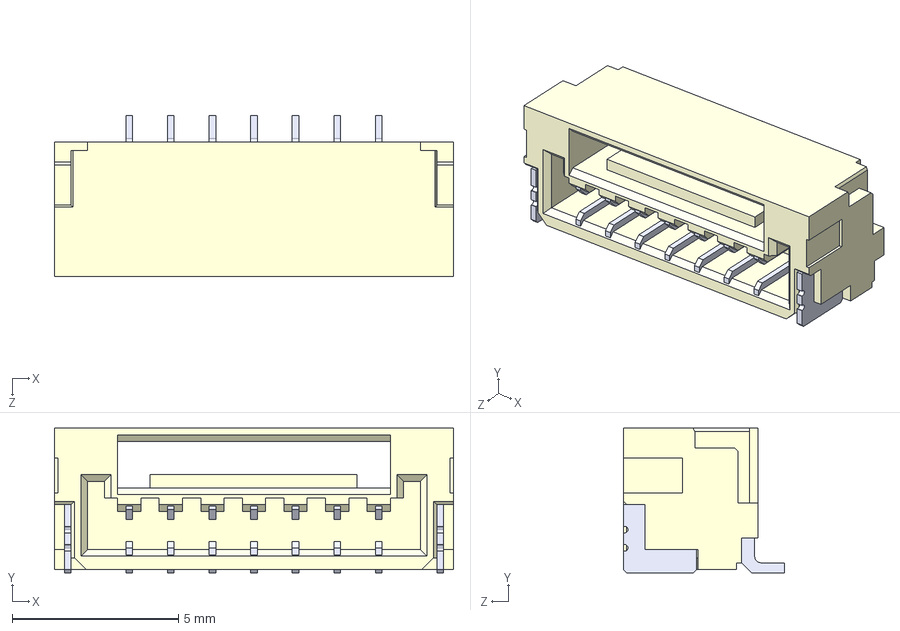
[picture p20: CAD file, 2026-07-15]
moteus-r4-parent/hw/x1/3d/SM07B-GHS-TB-LF--SN---3DModel-STEP-56544.STEP
12.0 x 4.35 x 4.85 mm

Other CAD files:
hardware/CAD/FlexNode.step
moteus-r4-parent/hw/c1/3d/DRB0008F.stp
moteus-r4-parent/hw/c1/3d/DSE0006A.stp
moteus-r4-parent/hw/c1/3d/S3B-PH-SM4-TB_LF__SN_.step
moteus-r4-parent/hw/c1/3d/SOD-523_STM.step
moteus-r4-parent/hw/c1/3d/XT30PW-M.step
moteus-r4-parent/hw/c1/r1.2/20240305-moteus-c1-r1_2.step
moteus-r4-parent/hw/controller/r4.3/20200729-moteus-controller-r43-mechanical.step
moteus-r4-parent/hw/controller/r4.5/20210124-moteus-controller-r45-mechanical.step
moteus-r4-parent/hw/n1/r1.2/20230226-moteus-n1-mechanical.step
moteus-r4-parent/hw/n1/r1.3/20230523-moteus-n1-r1_3-mechanical.step
moteus-r4-parent/hw/x1/3d/D0014A.stp
moteus-r4-parent/hw/x1/3d/DDA0008E.stp
moteus-r4-parent/hw/x1/3d/DRB0008F.stp
moteus-r4-parent/hw/x1/3d/DRL0008A.stp
moteus-r4-parent/hw/x1/3d/DSE0006A.stp
moteus-r4-parent/hw/x1/3d/FDMT80080DC.stp
moteus-r4-parent/hw/x1/3d/IND_6028-WE-LQS_WRE.step
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

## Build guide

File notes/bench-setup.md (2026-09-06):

# Bench setup

What is on the bench as of 2026-09-06 and the rules that were learned the hard way.

## Power
- **13 V bench adapter** into the motor bus input. Not the 9 V battery: the DRV8353S needs VM ≥ 9 V and an alkaline sags under load, giving phantom driver-undervoltage faults.
- Aux rails measured: 5 V buck and 3.3 V logic both stable from the adapter. Quiescent current is tens of mA.
- The 3.3 V pin on the FLASH header is the board's own rail. **Do not connect it to a USB-stick ST-Link's 3V3 pin** (that pin is an output on the clones; two regulators would fight). Leave it open.

## SWD header
FlexNode FLASH header, in order: **NRST · CLK · DIO · 3V3 · GND**.

| FlexNode | ST-Link V2 |
|---|---|
| GND | GND (connect first, disconnect last) |
| DIO | SWDIO |
| CLK | SWCLK |
| NRST | RST — see the rule below |
| 3V3 | open |

Reseating error that bit us: shifting a wire one pin over. CLK↔SWCLK and DIO↔SWDIO must not be swapped or offset.

> Gotcha, the NRST rule. A USB-stick ST-Link clone that is **not powered** (USB unplugged) drags NRST low and holds the STM32 in reset. Symptom: board dark on "standalone" power-up, springs to life the instant the ST-Link is plugged into the laptop. Conversely, with the ST-Link **powered**, NRST wired is good: it helps openocd connect, and pulling it made `init mode failed (unable to connect)` appear.
> Rule: keep NRST wired while the ST-Link is on the laptop. To run standalone, unplug the ST-Link entirely (pulling just GND also works, it floats the whole connector). Don't leave a dead ST-Link hanging off NRST.

Pulling any single jumper mid-session tends to unseat a neighbour. After touching the harness, run `probe` before anything else.

## ST-Link driver (Windows)
- Adapter: ST-Link V2 clone, VID 0483 / PID 3748. Windows binds nothing by default (Problem code 28).
- Bound to **WinUSB via Zadig** (Options → List All Devices → "STM32 STLink" → WinUSB → Install). Needs an admin prompt, so Aditya does that click. Zadig 2.9 exe was left at `Dev\flash\zadig-2.9.exe`.
- OpenOCD: xPack 0.12 installed with `winget install xpack-dev-tools.openocd-xpack`. The script finds `openocd.exe` under `%LOCALAPPDATA%\Microsoft\WinGet\Packages\xpack-dev-tools.openocd-xpack*`.
- "Target voltage: 2.2–2.3 V" in the openocd banner is the ST-Link reading its own floating VTref pin. Meaningless here; the real rail is 3.3 V.

## Flashing vs running
- Flashing with the ST-Link powered and all four wires in: fine, and the `reset` at the end of the flash **does** restart the board into the new image (verified 2026-09-06 by watching the new behaviour appear immediately after a flash).
- Standalone test = adapter power only, ST-Link fully disconnected. Watch the **first 3 seconds** after power-up: the status LED does one blue breath then goes dark, so a late glance sees a dark LED and learns nothing.
- Unplugging power **mid-flash** leaves a partially erased app region and the board won't boot. Not harmful; reconnect and reflash. The vector table and bootloader (first two images) survive if they had already verified.

## Not on the bench yet
- No CAN-FD adapter (no fdcanusb). Everything so far has been verified through SWD reads and the LED.
- No motor connected. No AS5047 soldered (back side). Power stage never energised.

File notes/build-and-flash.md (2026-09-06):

# Build and flash

## Build (WSL Ubuntu, from Windows)
The Bazel workspace is `moteus-r4-parent/`. Repo-pinned Bazel 7.4.1 via `tools/bazel`.

```
wsl.exe bash -c 'bash /mnt/c/Users/adity/Documents/CATBOT/FlexNode/Dev/moteus/tools/bench/build_fw.sh'
```

`build_fw.sh` runs `tools/bazel build --config=target //:target`, checks the real exit code (`${PIPESTATUS[0]}`, since `tail` lies), then calls `export_bins.sh` which objcopies the three flash images into `tools/bench/out/` (gitignored), mirroring upstream `fw/flash.py` exactly. A cached rebuild is ~25 s; a cold one a few minutes.

> Gotcha: `wsl.exe bash -c '...$VAR...'` from Git Bash mangles `$VAR` and `${PIPESTATUS[0]}` even inside single quotes. Anything non-trivial goes in a script file and is invoked as `bash /mnt/c/.../script.sh`. Also `wsl.exe bash -lc` (login shell) breaks here; use `bash -c`.

> Gotcha: Bash heredocs in the Claude tool occasionally fail with `unexpected EOF while looking for matching '` on larger bodies. Write files with the Write tool or a Python script file instead.

The build has `-Werror`. The moteus style rules apply: no trailing whitespace, blank lines truly empty. `grep -n -E "[[:space:]]+$" file` before committing.

## Image layout (512 KB G474, dual-bank, DBANK=1)
| Image | From | Address | Size (2026-09-06) |
|---|---|---|---|
| `out.08000000.bin` | `moteus.elf` `.isr_vector` | 0x08000000 | 472 B |
| `out.0800c000.bin` | `can_bootloader.elf` | 0x0800C000 | 8,368 B |
| `out.08010000.bin` | `moteus.elf` app sections | 0x08010000 | **437,808 B** |

Persistent config page is at **0x0807F000**. App window = 444 KiB → **~16 KiB free** as of `ef0d948`. Track this number in every commit message that changes firmware; it is the binding constraint (see [`open-questions.md`](open-questions.md)).

## Flash script
`tools/bench/flexnode-swd.ps1`, run from Git Bash (`!` prompt) as:

```
/c/Windows/System32/WindowsPowerShell/v1.0/powershell.exe -ExecutionPolicy Bypass -File C:/Users/adity/Documents/CATBOT/FlexNode/Dev/moteus/tools/bench/flexnode-swd.ps1 <mode>
```

| Mode | Writes? | Does |
|---|---|---|
| `probe` | no | chip ID, FLASH_OPTR, first flash words. **Run after any harness change.** |
| `probeslow` | no | same at 300 kHz SWD for a marginal link |
| `diag` | no | halts and samples PC ten times over ~2 s: alive vs stuck, and where |
| `verify` | no | byte-compares flash against the three images |
| `flash` | yes | programs + verifies all three images, then reset |
| `optionbytes` | yes | clears nSWBOOT0 → boot from flash regardless of PB8. **Required once per chip**, or it lands in the ROM bootloader (PB8/BOOT0 is held high by the I²C pull-up). Done on the first article; FLASH_OPTR reads `0xFBEFF8AA` |
| `ledtest` | yes | programs the 948 B bare-metal WS2812 chime at 0x08000000 (first-light test, no moteus) |
| `erase` | yes | mass-erase bank 0. Never implied by anything else |

The script disables openocd's gdb/tcp/telnet ports (a stale openocd once held port 3333 and every run failed with `couldn't bind gdb to socket`). It uses `reset_config none separate`: SWD only, NRST not driven by openocd.

Expect `** Verified OK **` three times. Anything else, see [`debugging-over-swd.md`](debugging-over-swd.md).

## Workflow that worked
1. Edit → `build_fw.sh` → confirm `BUILD_RC=0` and the new image size.
2. Aditya runs `flash` via `!`.
3. If the change is visible on the LED, watch the first 3 s after the reset. If it isn't, use `diag` or a symbol read.
4. Commit only after the board confirms. Commit message states the image size.

<!-- self: I once flashed a "temporary default on" bench build (led.imu_demo=1) to test with no CAN adapter, then reverted the default and reflashed before committing. That pattern is fine; just never commit the bench default. -->

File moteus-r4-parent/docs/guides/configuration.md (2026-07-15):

# Configuration

Before using a moteus controller for the first time, it is necessary to configure several key parameters. These parameters define operational limits, control behavior, and configure the system to match your specific application.

## Essential Configuration Parameters

The following parameters should be reviewed and will likely need to configured in a customized way for nearly every application.

### Position Limits

**`servopos.position_min` and `servopos.position_max`**

These define the bounds of motion which the controller will allow when in position control mode. Attempting to start beyond this region will fault, and if outside the region during operation, no torque will be applied to move further outside these limits.  If they are unwanted, `nan` should be used to disable them.

### Current Limits

**`servo.max_current_A`**

The maximum phase current to apply to the motor. This can be used to limit the maximum torque that the system is capable of producing, regardless of any command sent. Set this based on your motor's peak current rating and thermal capabilities.

### Velocity Limits

**`servo.max_velocity`**

Limits the maximum speed the motor is permitted to achieve before no torque is produced. This acts as a safety limit to prevent excessive speeds that could damage the motor or mechanical system.

**`servo.default_velocity_limit` / `servo.default_accel_limit`**

Controls how fast the motor can accelerate and spin in order to reach position and velocity targets. Bare boards ship with these unset, while development kits ship with human-eye pleasing values. Adjust these to match your application's performance requirements.

### Gearbox Scaling

**`motor_position.rotor_to_output_ratio`**

A gearbox scaling factor. A reducing gearbox should be configured with a number smaller than one (e.g., 0.25 for a 4x reduction gearbox). This affects reported position, speed, and torques, scaling them to represent the output shaft values rather than motor shaft values.

### Device Identification

**`id.id`**

The CAN-FD ID used by this device. Each controller on the bus must have a unique ID. Valid IDs range from 1 to 126.  If you set this to a value other than 1, be aware that unless your tview and controller firmware are newer than late 2025, you will need to restart tview with:

```
python -m moteus_gui.tview -t N
```

Where N is the new ID, in order to issue a `conf write` to save the
parameters.

### PID Parameters

**`servo.pid_position`**

The PID parameters for the position control loop. It will be necessary to tune these, it isn't hard, although it must be done after calibration is performed. You'll get to the [PID Tuning guide](../guides/pid-tuning.md) after completing the calibration process.

## Saving parameters

All parameters (including the ID) are temporarily stored in volatile memory that will be discarded after a power cycle.  To save those parameters to persistent storage, it is necessary to type:

```
conf write
```

Into the diagnostic console of tview.

## Additional Configuration

A larger set of parameters is documented in the [Configuration Parameters Reference](../reference/configuration.md), covering advanced features such as:

- Motor electrical characteristics
- Encoder configuration
- Temperature limits
- Communication settings
- Advanced control parameters

## Next Steps

After configuring these essential parameters, you should familiarize yourself with the encoder system and position feedback:

- [Encoder Overview](encoder-overview.md)

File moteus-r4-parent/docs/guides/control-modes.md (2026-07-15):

# Control Modes

The moteus controller offers flexible control modes to suit different robotics applications. By adjusting control gains and command parameters, you can optimize the controller for various use cases—from precise positioning and velocity control to high-bandwidth torque applications. This guide covers the recommended configurations for common control scenarios.

## Understanding Position Mode

The primary control mode for the moteus controller is an integrated position/velocity controller. The semantics of the control command are somewhat unorthodox, so as to be easily amenable to idempotent commands sent from a higher level controller. Each command includes the following parameters:

- **Position**: The desired position in revolutions
- **Velocity**: The rate at which the desired position changes in revolutions/s
- **Maximum torque**: Never use more than this amount of torque when controlling
- **Feedforward torque**: Give this much extra torque beyond what the normal control loop says
- **Stop position**: If non-special, never move the desired position away from this target
- **kp scale**: Scale the proportional constant by this factor
- **kd scale**: Scale the derivative constant by this factor
- **ilimit scale**: Scale the integrative limit by this factor
- **Velocity limit override**: If non-special, override the configured velocity limit, which constrains how quickly the target position is reached
- **Acceleration limit override**: If non-special, override the configured acceleration limit, which constrains how quickly the target position is reached

Additionally, the position may be set as a "special value" (NaN for floating point and the debug interface, maximal negative for integer encodings). In that case, the position selected is "wherever you are right now".

## Constant Acceleration Trajectories

Velocity and acceleration limits can be configured either globally, or
on a per-command basis which will cause moteus to internally generate
continuous acceleration limited trajectories to reach the given
position and velocity.  Once the trajectory is complete, the command
velocity is continued indefinitely.

=== "Diagnostic Protocol"

    ```
    # Move to position 1 then stop.  Accelerate/decelerate at 2Hz/s
    # and use a maximum velocity of 0.5Hz.
    d pos 1 0 nan a2 v0.5
    ```

=== "Python"

    ```python
    await controller.set_position(
        position=1,
        velocity=0,
        accel_limit=2,
        velocity_limit=0.5,
    )
    ```

=== "C++"

    ```cpp
    mjbots::moteus::Controller::Options options;
    options.position_format.accel_limit = mjbots::moteus::kFloat;
    options.position_format.velocity_limit = mjbots::moteus::kFloat;

    mjbots::moteus::Controller controller(options);

    mjbots::moteus::PositionMode::Command cmd;
    cmd.position = 1.0;
    cmd.velocity = 0.0;
    cmd.accel_limit = 2.0;
    cmd_velocity_limit = 0.5;

    auto result = controller.SetPosition(cmd);
    ```

Default values for acceleration and velocity limits can also be set in
configuration.

* `servo.default_accel_limit`
* `servo.default_velocity_limit`

## Velocity Control

To implement a velocity controller, each command should have the
"position" set to NaN (or equivalent integral encoding).  It is
recommended to configure `servo.max_position_slip` to a finite value
greater than or equal to 0 ([reference](../reference/configuration.md#servomax_position_slip)).
When it is larger, more external disturbances will be rejected, but
the controller will also "catch up" when the magnitude of external
disturbances is decreased.

**Example:**

=== "Diagnostic Protocol"

    ```
    d pos nan 2 nan
    ```

=== "Python"

    ```python
    await controller.set_position(
        position=math.nan,  # NaN for velocity mode
        velocity=2.0,       # 2 revolutions/second
        query=True
    )
    ```

=== "C++"

    ```cpp
    mjbots::moteus::PositionMode::Command cmd;
    cmd.position = std::numeric_limits<double>::quiet_NaN();
    cmd.velocity = 2.0;  // 2 revolutions/second

    auto result = controller.SetPosition(cmd);
    ```

## Torque Control

For a pure torque control application, the PID gains of the position control loop must be set to 0.  One way to accomplish that is by sending the `kp_scale`, `kd_scale`, and `ilimit_scale` values to 0.

=== "Diagnostic Protocol"

    ```
    # Command a torque of 0.1 Nm
    d pos nan 0 nan p0 d0 i0 f0.1
    ```

=== "Python"

    ```python
    await controller.set_position(
        position=math.nan,
        velocity=0,
        kp_scale=0.0,
        kd_scale=0.0,
        ilimit_scale=0.0,
        feedforward_torque=0.1,
    )
    ```

=== "C++"

    ```cpp
    mjbots::moteus::Controller::Options options;
    options.position_format.kp_scale = mjbots::moteus::kFloat;
    options.position_format.kd_scale = mjbots::moteus::kFloat;
    options.position_format.ilimit_scale = mjbots::moteus::kFloat;
    options.position_format.feedforward_torque = mjbots::moteus::kFloat;

    mjbots::moteus::Controller controller(options);

    mjbots::moteus::PositionMode::Command cmd;
    cmd.position = std::numeric_limits<double>::quiet_NaN();
    cmd.velocity = 0.0;
    cmd.kp_scale = 0.0;
    cmd.kd_scale = 0.0;
    cmd.ilimit_scale = 0.0;
    cmd.feedforward_torque = 0.1;

    auto result = controller.SetPosition(cmd);
    ```

**Caveat**: Using external torque control will be much lower
bandwidth than using the internal position controller of moteus (~15x
lower bandwidth if maximal CAN-FD update rate is achieved).  Thus, a
system will usually perform better if as much of the desired control
law as possible is formulated in terms of the built in position
controller.

If the system will never perform anything *but* torque control, then the PID gains can be set to 0 in configuration.

* `servo.pid_position.kp`
* `servo.pid_position.kd`
* `servo.pid_position.ilimit`

## Jerk Limited Trajectories

moteus only supports acceleration limited internal trajectories.  To
approximate a constant jerk trajectory, the host processor should send
a sequence of piecewise linear constant velocity trajectories which
approximate the desired one.  This would be done by sending commands
consisting of at least a position and velocity at some moderate to
high rate while disabling the internal velocity and acceleration
limits.

## Low Speed or Precise Positioning

For either operation at very low speeds, or when precise positioning
performance is desired, it is recommended to configure a non-zero `ki`
and `ilimit` term in the position controller
([reference](../reference/configuration.md#servopid_position)).  This will compensate for cogging
torque (at the expense of overall torque bandwidth).  It may also be
beneficial to select a higher value for calibration bandwidth.

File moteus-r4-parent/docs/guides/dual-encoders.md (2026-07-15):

# Dual Encoder Configuration

Often moteus is used in applications where a gearbox or other reducer is used between the rotor and the final plant.  In those situations it can be valuable to have a secondary encoder measuring the output of the reducer:

**Absolute positioning**: With only an encoder on the rotor, it is not possible to know absolutely where the output is.

**Improved accuracy or sensing performance**: The onboard encoder included with moteus is sufficient for commutation for nearly all motors, however some applications may require lower position or velocity sensing noise or higher resolution in order to achieve accurate very slow movements, or very accurate positioning.

This section will cover how to set up several common dual encoder configurations.

## Important factors when configuring dual encoders

1. **Sign match**: moteus requires that the sign of all encoders match.  Those must be configured manually in `motor_position.sources.X.sign`.  To verify the signs are correct, plot `motor_position.sources.X.filtered_value` for all configured encoders, spin the system by hand, and verify that all plots move in the same direction.

2. **Offset match**: If the absolute values of multiple encoders must be related, such as for a disambiguation configuration, then the offsets must be matched so that the encoders read 0 at the same time.  These offsets must be manually configured in `motor_position.sources.X.offset`.  To verify they are correct, plot `motor_position.sources.X.filtered_value` for all configured encoders, spin the system by hand to the zero point, and verify that all encoders read 0.

## Onboard + 8x reducer + MA600 on-axis - Disambiguation

In this configuration, the rotor is sensed with the moteus onboard encoder and the output is sensed with an MA600 on-axis encoder.  Assuming low backlash, the output positioning is performed from the onboard encoder and the output encoder is only used for disambiguation.  This results in the best performance since the effective resolution of the onboard encoder is multiplied by the gear reduction and will be much better than the MA600 on the output.

The MA600 is attached to the aux2 port on one of the moteus-c1 [(c1 pinout)](../reference/pinouts.md#moteus-c1), moteus-n1 [(n1 pinout)](../reference/pinouts.md#moteus-n1), or moteus-x1 [(x1 pinout)](../reference/pinouts.md#moteus-x1).

This pinout is the one accomplished if using the cable included with the [mjbots MA600 breakout board](https://mjbots.com/products/ma600-breakout).

If starting from a factory default configuration, first, configure the
aux2 port:

```
aux2.pins.0.mode 1  # spi
aux2.pins.1.mode 1  # spi
aux2.pins.2.mode 1  # spi
aux2.pins.3.mode 2  # spi_cs
aux2.spi.mode 5     # ma600
aux2.spi.rate_hz 6000000
```

Then, configure motor_position:

```
motor_position.sources.1.aux_number 2
motor_position.sources.1.type 1
motor_position.sources.1.cpr 65536
motor_position.sources.1.reference 1  # output
motor_position.rotor_to_output_ratio 0.125
motor_position.output.reference_source 1
```

The sign and offset of the MA600 will need to be matched to the onboard encoder as per [the above section](#match).

## Onboard + 10x reducer + AksIM-2 on output

In this configuration, the onboard encoder is used to sense the rotor, and an AksIM-2 encoder from RLS is used on the output.  The AksIM-2 has much better accuracy and noise performance than the onboard on-axis encoder, and thus this configuration could be used for applications where either very accurate positioning is required, or very precise low speeds are required.

The AksIM-2 is attached to the GH-6 RS422 connector on a moteus-n1 [(n1 pinout)](../reference/pinouts.md#moteus-n1) or moteus-x1 [(x1 pinout)](../reference/pinouts.md#moteus-x1).

moteus is compatible with AksIM-2 encoders configured as follows:

- **Communication Interface**: SF - Asynchronous Serial, RS422, 5V
- **Communication Protocol Variant**: F - 1000 kbps
- **Resolution**: <= 19B, no multiturn support

If starting from a factory default configuration, first configure the aux1 port.

```
aux1.pins.3.mode 3 # uart
aux1.pins.4.mode 3 # uart
aux1.uart.mode 1 # aksim2
aux1.uart.baud_rate 1000000
aux1.rs422 1
```

Then configure motor_position:

```
motor_position.rotor_to_output_ratio 0.1
motor_position.sources.1.aux_number 1
motor_position.sources.1.type 2          # uart
motor_position.sources.1.cpr 4194304     # used by moteus for all AksIM-2
motor_position.sources.1.reference 1     # output
motor_position.output.source 1
```

The sign and offset of the AksIM-2 will need to be matched to the onboard encoder as per [the above section](#match).

## Hall + 10x reducer + Off axis MA600

In this configuration, hall effect encoders are used to sense commutation and an MA600 is used in conjuction with a diametrically magnetized ring magnet for output positioning.  It is designed as one of the lowest cost options for a hollow axis actuator with a gear reduction, as the off-axis MA600 has minimally acceptable performance as does the hall effect sensors.

The MA600 is connected to AUX1 on a moteus-n1 [(n1 pinout)](../reference/pinouts.md#moteus-n1) or moteus-x1 [(x1 pinout)](../reference/pinouts.md#moteus-x1) and the hall effect sensors are connected to AUX2.

First, we will configure the hall effect sensors and calibrate them.

```
aux2.pins.0.mode 6  # hall
aux2.pins.0.pull 1  # pull_up
aux2.pins.1.mode 6  # hall
aux2.pins.1.pull 1  # pull_up
aux2.pins.2.mode 6  # hall
aux2.pins.2.pull 1  # pull_up
aux2.hall.enabled 1
motor_position.rotor_to_output_ratio 0.1
motor_position.sources.0.aux_number 2
motor_position.sources.0.type 4  # hall
```

Then, the hall effect sensors are calibrated:

```
python -m moteus.moteus_tool -t 1 --calibrate --cal-motor-poles 30
```

Now we will configure the MA600.

```
aux1.pins.0.mode 1  # spi
aux1.pins.1.mode 1  # spi
aux1.pins.2.mode 1  # spi
aux1.pins.3.mode 2  # spi_cs
aux1.spi.mode 5     # ma600
aux1.spi_rate_hz 6000000
motor_position.sources.1.aux_number 1
motor_position.sources.1.type 1  # spi
motor_position.sources.1.cpr 65536
motor_position.sources.1.reference 1  # output
```

Then, before configuring the MA600 to be used for output, match the sign of the MA600 and hall effects according to [the procedure here](#match).

For an off-axis MA600, BCT tuning should be performed, and non-linear compensation may be performed.

```
moteus$ ./utils/measure_ma732_bct.py
```

To peform non-linear compensation, you can use:

```
moteus$ ./utils/compensate_encoder.py
```

Finally, the MA600 can be configured as the output source:

```
motor_position.output.source 1
```

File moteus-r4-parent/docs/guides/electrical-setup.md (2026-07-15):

# Electrical Setup

To use moteus without damage, proper care must be paid to the electrical connections and configuration.  This section describes how.

## Electrical Connections

**Motor**: Phase wires for the motor should be soldered to the pads labeled A, B, and C. The order does not matter. The location of the pads varies between controllers.  An inline connector, like an MR30, MR60, or bullet connectors can be used if repeated disconnection is desired.

**Power**: Power is provided via either the onboard XT30 connector, or on board-mountable moteus controllers, via the power pads that are interleaved with the A, B, and C phase pads.  The power input is *NOT* protected against reverse polarity.  Polarity should be triple checked before applying power, or irreversible damage may result.  XT30 connectors have a clear '+' and '-' marking on them which can be used to identify the positive and negative input.

If you are unsure, pinout diagrams for all controllers can be found here: [Pinout diagrams](../reference/pinouts.md)

!!! note "Hot plugging"
    It is important to *never* hot plug an XT30 connector.  The XT30 connector (and all connectors which are not anti-spark), should be connected *before* power is applied.  If you see or hear a spark, you have applied power in the wrong order.  See the below section on inrush current management.

## Soldering and cable construction techniques

moteus controllers can be damaged when improper techniques are used to attach wires to them, or improper techniques are used to construct power cables.

### Phase Wire Soldering

The connections between moteus and the motor under control must be high quality.  Poor quality solder joints can cause intermittent changes in resistance, sparking, and high voltage transients.  High quality solder joints require:

* Sufficient flux to clean oxides off of the wire and the via
* Sufficient temperature so that the entire wire and via is hot enough for the solder to wet all surfaces

For the former, it is often necessary to add copious amounts of additional flux in addition to the rosin core inside many solders.  For the latter, a high power soldering iron, with a fat tip, and what seems like a long time may be necessary.  The temperature is definitely insufficient if solder touched to any part of the via or wire does not melt and wick instantly.  Usually a small amount of solder is placed between the tip and wire to act as a heat transfer agent.  Then the iron rests on the via and wire for between 5-30s until it looks like the initial solder has wicked fully into the via.  Then additional solder can be added until it forms a clean smooth fillet around the entire via wicking up to the wire.

When complete, the back side of the hole can be examined, and if successful, solder will have wicked partially down out of the via onto the other side forming a clean, smooth fillet there as well.

A demonstration of this can be found in the following video: [https://www.youtube.com/watch?v=mZ9w_TaWmjQ](https://www.youtube.com/watch?v=mZ9w_TaWmjQ)

{{ youtube("mZ9w_TaWmjQ") }}

### Power Cable Construction

When constructing power cables using XT30 connectors, it is critical that solder joints be sound, otherwise intermittent connectivity can result.  This can cause sparking and high voltage transients.  The soldering principles are the same as in the phase wire soldering section above.

A demonstration of XT30 soldering can be found in the following video:
[https://www.youtube.com/watch?v=f6WtDFWuxuQ](https://www.youtube.com/watch?v=f6WtDFWuxuQ)

{{ youtube("f6WtDFWuxuQ") }}

### Power Connectorization

For moteus to operate without damage, the XT30 connectors used to transmit power must make a solid connection that is non-intermittent.  As with poor soldering, an intermittent connection can cause inductive spikes, which will destroy components on the controller.

When connectors are functional, moderate insertion force should be required and the connectors should not "wiggle" much after insertion.

The XT30 is not rated for any significant amount of mechanical force when mated.  For any application where cables may flex, strain relief should be used such that no force is applied to the connector.  The connector may be damaged if a system goes "out of control" even in one instance, although milder mechanical stress may cause accelerated fatigue and failure.

If sparks are observed, that is *definitely* a problem and the system should be powered off until the connectors can be replaced and mitigations made for what led to that event.

Genuine AMASS connectors are rated for 1000 insertions assuming no other mechanical damage, however off-brand connectors may have worse tolerances and may not make a reliable connection for even one insertion.

### Long daisy chains

When connecting more than 3 moteus controllers or servos in a system on a single power or CAN chain, additional factors should be considered.

1. It is recommended to use T-spliced power instead of using the daisy chained power connectors for chains greater than 3 units.  Small connector mis-seating or micro-arcing will cause magnified effects with long chains of controllers.

2. CAN bus electrical performance can be a limiting factor.  To operate at the default 5Mbps, you will need to ensure that CAN wires are twisted, all crimps are high quality, and that termination is installed.  Split termination may be required, where two 60 ohm resistors are connected in series with a small filter capacitor connected between the center tap of the resistors and ground.  A 4.7nF capacitor is recommended.  If that is insufficient, BRS can be disabled to operate only at 1Mbps.  With `moteus_tool` or `tview`, the `--can-disable-brs` flag can be used.

mjbots sells a CAN terminator that can be used for this purpose: [https://mjbots.com/products/jst-ph3-can-fd-terminator](https://mjbots.com/products/jst-ph3-can-fd-terminator)

## Inrush current management

moteus controllers have large DC bulk capacitance with low ESR, this is how they can achieve their small form factor.  As a result, care must be taken when applying power.  If a connector is "hot-plugged" extremely large transient currents can develop which may damage the moteus or other components in the system.  These challenges are magnified when more than one moteus controller is attached to the same power bus.

Potential solutions:

**Power Supply**: If a wall power supply is used, it can be relied upon to provide a "soft start" functionality.  Ensure that all moteus controllers are attached to the power supply *before* enabling the supply by turning it on or plugging it into a wall.

**Anti-spark connectors**: There exist anti-spark connectors like the XT90-S, which have a power resistor built in which makes contact before main power is applied.  These can be used, but have several drawbacks:

1. The proper order of connection must always be obeyed.  Unless the XT90-S is connected *last*, then inrush transients may result.
2. If the power rating on the built-in resistor is not respected, it will silently fail, resulting in no pre-charge protection at all.

**Active pre-charge circuits**: mjbots sells the [mjpower-ss](https://mjbots.com/products/mjpower-ss) and [power_dist](https://mjbots.com/products/mjbots-power-dist-r4-5b), both of which have the primary function of gradually precharging capacitive loads.  Other active pre-charge systems may also be viable.

## Regenerative braking safety

moteus can be commanded to sharply decelerate loads, either directly in response to commands, or due to external disturbances.  When braking a load, moteus by default applies the generated power to the input DC bus.

If there is nowhere for this power to go, this can cause problems.  The voltage can increase without bound, which in mild cases will cause the CAN transceiver on all devices connected to the bus to fail, and in severe cases can explode the main FETs or other components on the board.

Here's what you should know about the facilities moteus has to deal with this, and what you can do to make your design safer.

### Software protections

moteus has several configurable mechanisms to limit regenerative voltage rise.  For full tuning details, see [Troubleshooting Overvoltage Fault 34](../troubleshooting/overvoltage-fault-34.md).

**Acceleration limits**: Setting `servo.default_accel_limit` (or per-command `accel_limit`) controls how quickly braking torque is applied.  This is the most direct way to limit the rate of regenerative power injection.

**Regen power limiting**: Setting `servo.max_regen_power_W` limits how much power is allowed to flow back to the bus during braking.  Excess energy is pre-emptively dissipated in the motor windings via d-axis current injection.  For a supply that cannot absorb any regenerative energy, set this to a small number like `10` or even `0`.

**Flux braking**: When bus voltage rises above `servo.max_voltage - servo.flux_brake_margin_voltage`, moteus dissipates energy in the motor windings to resist further voltage rise.  This is controlled by `servo.flux_brake_margin_voltage` and `servo.flux_brake_resistance_ohm`.

### Hardware design considerations

The following design considerations can be used to minimize the risk of damage to hardware in the event of overvoltage.  These are not a substitute for validation in progressively more demanding situations, but they can help you start off in a good place.

- *Tightly scope the over-voltage fault / flux braking*: The configuration parameter `servo.max_voltage` can be lowered for all devices on the bus.  This will both cause a fault if the voltage exceeds this value and in conjunction with `servo.flux_brake_margin_voltage`, select the point at which moteus will attempt to dissipate energy to prevent an overvoltage scenario.  It is recommended to set this to no less than 5V above the maximum expected supply voltage.

- *Power from a battery, not a PSU*: When not charged, batteries are capable of sinking current to minimize over-voltage transients.  However, if the battery is fully charged, most battery management systems drastically reduce the allowable charging current.  Thus, a battery is only useful as a mitigation if it is never charged above say 75 or 80% state of charge.

- *Decrease overall system voltage*: If you run the moteus controller with say a 10S battery, the peak input voltage can be as high as 42V.  That does not leave very much margin for regenerative loads.  For applications that experience sharp regenerative loads and do not have a battery capable of charging always attached, it is recommended not to exceed 8S (33.6V peak).

- *Use a supply which can sink as well as source*: Powering from an inexpensive lab supply is the most dangerous, as they typically have no ability to sink current, only source it.  A "two quadrant" supply is the necessary device.

## Next Steps

After completing electrical connections, proceed to [software installation and configuration](software-installation.md) to begin using your moteus controller.

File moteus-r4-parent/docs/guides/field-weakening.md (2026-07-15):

# Field Weakening

## Background

moteus controllers are used to operate permanent magnet synchronous motors (PMSM).  In normal operation, the maximum no-load speed that can be achieved by a PMSM is determined by:

```
max_speed_hz = Kv * supply_voltage / 60
```

With moteus, there are two further constants that are multiplied in, the space vector modulation constant, and the maximum modulation factor constant.  As of 2026, these combine to roughly:

```
k_svpwm * k_maxmod ~= 0.8
max_speed_hz = k_svpwm * k_maxmod * Kv * supply_voltage / 60
```

This limit occurs because the controller can only apply torque when the supply voltage is greater than the back-EMF generated by the motor while it is in motion.  It is possible to apply current in the non-torque generating axis (the D axis) to reduce the effective back-EMF constant and thus increase the effective Kv constant.  This effect is called "field weakening".  The magnitude of this effect depends upon motor construction.  Typically, interior permanent magnet synchronous motors (IPMSM) are capable of relatively large amounts of field weakening at moderate power expenditure.  Most hobby and low-cost brushless motors are surface permanent magnet synchronous motors (SPMSM) for which field weakening is sometimes possible at reasonable power budget and sometimes not.

moteus has support for operating in the field weakening regime and thus extending the maximum achievable speed a motor can achieve for a given supply voltage.  This has several caveats:

- **Power**: The power required to operate a motor will be the same or larger when field weakening is enabled.  When field weakening is used, additional power will start to be used slightly before the no-load speed so that maximum torque can be achieved.  At higher speeds, the power consumed by the supply and dissipated as thermal energy in the motor and controller can be very large.  The amount used is also proportional to the maximum configured current, so if the full amount is not required for your application, lowering `servo.max_current_A` may be helpful.
- **Calibration**: Field weakening relies on the specific value of the D axis inductance.  For many motors, this value can change significantly at different values of D axis current.  In order to operate stably, moteus requires a longer calibration step to measure this D axis inductance saturation scale effect.
- **Stability**: For some motors, moteus must be calibrated at a higher `--cal-bw-hz` to operate at a speed in the field weakening regime than would be necessary if the supply voltage were high enough to not require field weakening.  Calibrating at a higher `--cal-bw-hz` will result in increased audible noise at all speeds.
- **Hardware Limits**: Even when field weakening is enabled, moteus will restrict the maximum speed to be no more than what could be achieved if the used moteus controller was supplied with its maximum rated input voltage.  Thus if you are already operating your controller near the maximum rated board voltage, there may be minimal or no gains in speed achievable through field weakening.

The [moteus performance analysis tool](https://mjbots.github.io/moteus/mpat.html) can be used to estimate the power required and performance when field weakening is enabled or disabled for a given system.

## Usage

Using field weakening with moteus requires calibration procedures and configuration values to be set.  Additionally, there are diagnostic values which can be monitored.

### Calibration

When calibrating, it is recommended to perform the D axis inductance scale procedure.

```
python -m moteus.moteus_tool -t 1 --calibrate --cal-measure-ld-saturation
```

This will require several minutes of operation and may require active cooling of the motor or controller in order to succeed.

The calibrated `L_d` scale will be nearly the same for all copies of a single motor design, so this parameter can be copied from controller to controller so that the calibration only needs to occur once across multiple instances.

```
servo.inductance_d_scale
```

### Configuration

To enable field weakening operation, use this configuration:

```
servo.fw.enable 1
servo.bemf_feedforward 1
```

`servo.bemf_feedforward` should be set to 1 when field weakening is used so that the controller can properly anticipate the back-EMF voltage and maintain stable operation at high speeds.

### Monitoring

When in operation, there are some diagnostic values that can be monitored:

`servo_stats.motor_base_velocity`: This is the speed at which field weakening begins.  Above this speed, additional power will be applied to the motor, increasing with speed, to enable operation above the no-load speed.

`servo_stats.motor_max_velocity`: This is the maximum speed moteus will permit.  Note that this is not a continuous rated speed, as temperature of the board or motor may rapidly exceed configured limits when operating at large levels of field weakening.

`servo_stats.fw.id_A`: The amount of D axis current currently being used to decrease the back EMF constant.

## Limitations

- **Board maximum voltage**: moteus limits field weakening speed such that the back EMF produced by the motor never exceeds `servo.max_voltage` minus an appropriate margin
- **Maximum D axis current**: `servo.fw.max_current_ratio` is multiplied by `servo.max_current_A` to determine the maximum D axis current that can be used for field weakening
- **Thermal performance**: Field weakening operates by applying *more* power to the motor.  This means it will increase in temperature faster, reducing thermal performance.

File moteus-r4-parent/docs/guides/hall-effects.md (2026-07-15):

# Motor with Hall Effect Sensors

Many motors include hall effect sensors used to provide commutation information to motor controllers.  moteus is able to use hall effect sensors for both commutation and output positioning.  First, some caveats:

**They may not be needed**: Just because a motor has hall effect sensors built in, does not mean you need to use them.  If you can use the on-axis magnetic encoder integrated into moteus by mounting moteus appropriately relative to the rotor, that will always give better results than using hall effect encoders.

**You will likely need additional hardware**: Most configurations with hall effects will require additional filtering capacitors, placed near moteus, between each signal line and ground.  1nF is a recommended starting point.  They can be added either in the wire harness, or on unpopulated 0402 pads on the moteus-c1, moteus-n1, and moteus-x1.

**Hall effect sensors used for output positioning have very poor low velocity performance**: While hall effect sensors are minimally useful for commutation and higher speed output operation, they will provide poor performance when used as an output encoder at low speeds.  That means many position control applications, which are inherently often at low speed, will give poor results.

**moteus-r4 cannot easily drive many hall effect sensors**: moteus-r4 specifically has only 3.3V supply for external devices, whereas most hall effect encoders require 5V.  Further, the only means of connecting hall effect sensors to moteus-r4 are using unpopulated pads on the back of the board, and *not* using the onboard encoder.  Other moteus products do not have these specification limitations regarding supply voltage and connectors.

If using hall effects for commutation or output positioning is still desired, the below configurations can get you started.

## aux2 configuration ##

This configuration uses hall effect sensors connected to the aux2 GH7
connector for both commutation and output positioning.

moteus-c1 [(c1 pinout)](../reference/pinouts.md#moteus-c1), moteus-n1 [(n1 pinout)](../reference/pinouts.md#moteus-n1), and moteus-x1 [(x1 pinout)](../reference/pinouts.md#moteus-x1) all have an aux2 GH7 connector that can provide 5V output and has 5V tolerant IO pins.  The typical wiring diagram looks like the below, although the hall connector is "nominal" as there is no real standard:

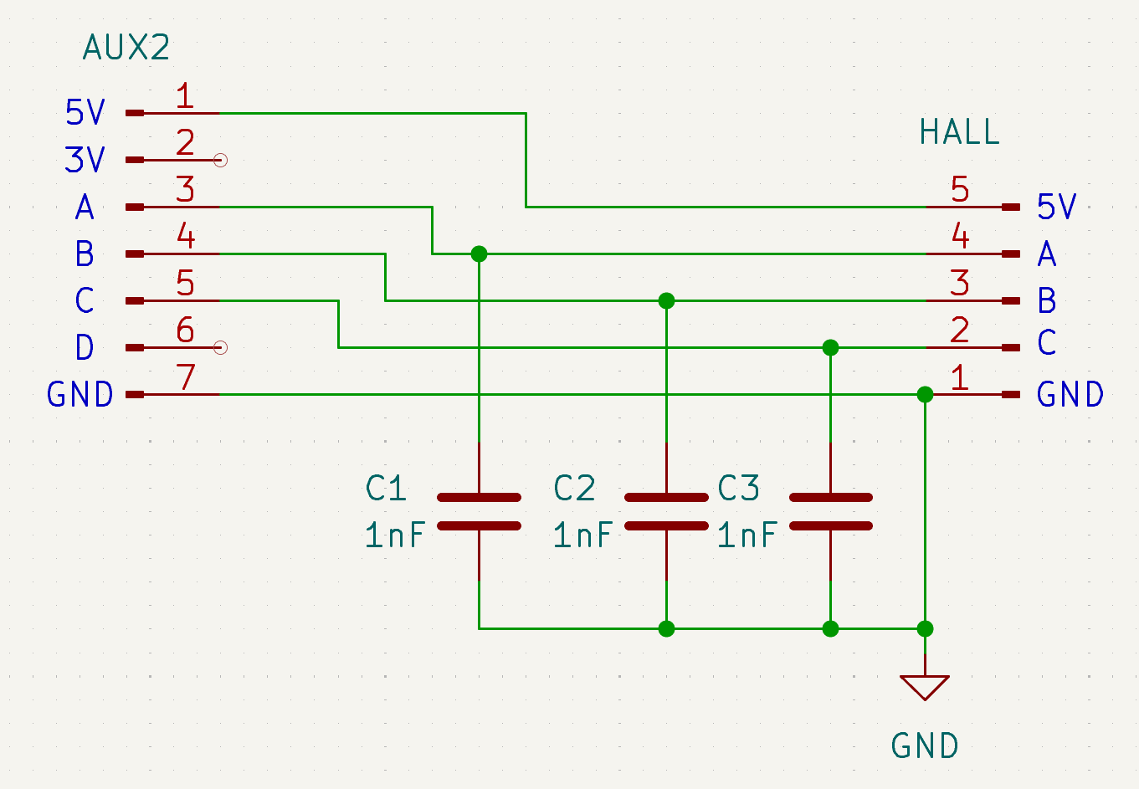
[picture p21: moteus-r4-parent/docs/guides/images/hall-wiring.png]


As mentioned above, either 1nF capacitors should be installed in the harness between each signal line and ground, or installed on the appropriate unpopulated pads on the board.

The following aux2 configuration parameters should be set.

```
aux2.pins.0.mode 6  # hall
aux2.pins.0.pull 1  # pull_up
aux2.pins.1.mode 6  # hall
aux2.pins.1.pull 1  # pull_up
aux2.pins.2.mode 6  # hall
aux2.pins.2.pull 1  # pull_up
aux2.hall.enabled 1
```

Then motor_position is configured as follows:

```
motor_position.sources.0.aux_number 2
motor_position.sources.0.type 4  # hall
```

Finally, when calibrating, the number of poles is required to be
specified.

```
python -m moteus.moteus_tool -t 1 --calibrate --cal-motor-poles 30
```

## Advanced: Dual Encoder Setup

A more performant configuration may use the hall effect sensors for commutation and a different encoder measuring the output position.  That is not directly described here, but you can look at the [Dual Encoders](dual-encoders.md) guide as well as the [encoder reference](../reference/encoders.md) to understand how to configure it.

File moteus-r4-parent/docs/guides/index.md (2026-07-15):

# Using moteus

Step-by-step guides for setting up and using moteus.

- [Mechanical Setup](mechanical-setup.md) - Physical installation
- [Electrical Setup](electrical-setup.md) - Wiring and power connections
- [Software Installation](software-installation.md) - Installing client software
- [Configuration](configuration.md) - Basic configuration
- [Encoder Overview](encoder-overview.md) - Understanding encoder options
- [Calibration](calibration.md) - Motor calibration procedure
- [PID Tuning](pid-tuning.md) - Tuning position and velocity control
- [Control Modes](control-modes.md) - Position, velocity, and torque modes

## Advanced Configuration

- [Motor with Hall Effects](hall-effects.md) - Using hall effect sensors
- [Dual Encoders](dual-encoders.md) - Separate motor and output encoders

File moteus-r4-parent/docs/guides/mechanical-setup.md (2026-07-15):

# Mechanical Setup

To use the onboard on-axis encoder integrated with moteus, the controller must be mounted with care to ensure proper alignment and ongoing registration.

## Mechanical Mounting

If using the default onboard encoder, the following steps must be taken:

1. A diametrically magnetized sense magnet should be attached to the rotor (*NOT* the output of any reducer or linkage). The fastening must be rigid, allowing no slip. Adhesive is generally required, cyanoacrylate or epoxy can be used.
2. The moteus controller must be mounted so that the encoder is (a) centered laterally on the sense magnet and (b) has an air-gap of approximately 2mm. This mount must be rigid and allow no slip.

!!! note "moteus-r4 mounting"
    Unlike other moteus controllers, the moteus-r4 encoder is *not* centered under the bolt pattern, check the [2D CAD for details](https://github.com/mjbots/moteus/blob/main/hw/controller/r4.5/20210124-moteus-controller-r45-mechanical.pdf).

!!! note "3D printed mounts"
    If using 3D printed mounts, care should be taken to ensure the mount does not warp.  PLA and other low temperature filaments will warp under load at room temperature, and will do so even more when exposed to thermal heating like from a motor controller.  It is recommended to use PETG, PC, or a filament designed to not warp at the operating temperature you intend.

## Additional Considerations

There are additional considerations when mounting, some mostly common sense, and some unique to moteus.

### Protection from debris and stray conductors

It is advisable to mechanically shield moteus controllers from the environment during operation to prevent contact with stray conductors, dirt, or debris.  Contact with any of these things while the system is energized can result in failure.

Similarly, manipulating or working on the system while it is energized should be avoided.

### moteus-n1 light sensitivity

moteus-n1 has a voltage regulator which is light sensitive and will fail when exposed to sunlight.  The enclosure used to house the system should be opaque.  If for some reason an enclosure can not be used, opaque expoxy can be placed over the voltage regulator IC.

moteus-c1, moteus-r4 and moteus-x1 have no light sensitivity considerations to take into account.

## Next Steps

Once mechanical mounting is complete, proceed to [Electrical Setup](electrical-setup.md) to connect the motor phase wires and power.

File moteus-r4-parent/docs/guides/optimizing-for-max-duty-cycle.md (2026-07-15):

# Optimizing for maximum duty cycle

## Background

In some cases, it is important that moteus be able to achieve the maximum possible speed on a given motor without resorting to field weakening.  The controller is limited in how much of the supply voltage it can apply to the motor.  By definition the multiple that it can supply is less than 1.  This multiple is constrained by moteus's requirement to be able to sense the current flowing to the motor in order to perform field oriented control. Two factors bound this constraint:

1. The current can only be sensed when the "low" side MOSFET is switched on.  Thus, the low-side MOSFET must be on long enough for ADC to trigger and complete its sampling process.
2. The input to the ADC is a current sense amplifier (CSA) onboad moteus.  This amplifier has a gain dependent settling time that must be respected.  This settling time must complete *before* the ADC sampling process starts.

## Tuning parameters

To maximize the available duty cycle, there are two parameters that can be controlled.

1. `servo.pwm_rate_hz`: The lower the PWM rate, the higher the available duty cycle.  Setting it to the minimum of 15000 Hz is the limit.  Lower PWM rates decrease the control update rate and decrease the peak power the board can support.

2. `drv8323.csa_gain`: The current sense amplifier gain, which can be one of [5, 10, 20, 40].  The default is 20.  Lowering this to 10 gives the maximum duty cycle benefit at the expense of increased current sense noise.  This will result in more audible noise from the system and lower available torque control bandwidth.

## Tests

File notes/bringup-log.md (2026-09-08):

# Bring-up log

Chronological, absolute dates. Newest at the bottom. Each entry says what was **validated on hardware**, not what was written.

## 2026-07-21 — compat layer
Board identity hardcode, autodetect deletion, AS5047 CS → PC6, drive-side phase re-pair (netlist-verified on paper). Builds green. Nothing run on hardware.

## 2026-07-24 — vsense rescale
As-built R30 = 1.2 kΩ (designer-confirmed, not 4.7 kΩ). Compensated in firmware, no rework. Needs a `bus_V` vs DMM check at first CAN contact.

## 2026-09-06 — first article boots (commits `5f32b08` → `ef0d948`)
Board on a 13 V bench adapter; 5 V and 3.3 V rails stable.
- SWD probe: STM32G47x, IDCODE `0x20036469`, 512 KiB dual-bank, RDP0, factory option bytes, blank flash.
- nSWBOOT0 cleared (boot from flash; PB8/BOOT0 sits high on the I²C pull-up). FLASH_OPTR now `0xFBEFF8AA`.
- Bare-metal 948 B WS2812 chime on PF0: **first light, first try.** Proves boot from flash, PF0 wiring, 16 MHz HSI on frequency.
- moteus FlexNode image flashed and running. Main loop healthy (PC sampling). Servo in `kStopped`.
- WS2812 status driver: correct colours confirmed (default soft blue), fault-code blink designed (not yet observed: no fault has occurred), **one-shot blue breath on OK then dark** confirmed after the `0`-bit timing fix.
- **LSM6DS3TR-C IMU** on aux2 I²C: WHO_AM_I answers, samples flow; verified by the tilt→hue demo with the board in hand. No CAN adapter involved.
- Register block skeleton (0x080/0x081, IMU, pixel, 0x0FF) compiled in. **Unverified over CAN.**
- Standalone power-up (ST-Link fully disconnected) confirmed working once the NRST rule was understood.
- Portfolio/site updated with the first-light photo by a subagent (site commits `1ea15c2`, `ae1d7af`, `8bfc4c6`).

Image at end of day: 437,808 B, ~16 KiB free.

(The "still gated" table that stood here as of 2026-09-06 is superseded by the one at the end of the file.)

## 2026-09-07 02:20 IST — open-loop motor test image prepared

First-energisation bench image built on branch `bench/openloop-test`, commit `843566b`. Not on
main. At the time of writing the power stage had never been energised; the runs are in the next entry.

Motor GIM 8108-8, no encoder (AS5047 unsoldered, magnets not arrived), 13 V 1 A current-limited
supply. Uses stock `kVoltageFoc` (mode 7) — commanded electrical angle + voltage, sinusoidal, **no
encoder, no `theta_valid` check** — commanded through the same `BldcServo::Command()` entry the CAN
register writes use. **FOC / PWM / modulation / current-sense / gate-driver code untouched.**

Safe voltage, computed not guessed: R phase-to-phase 0.439 Ohm -> 0.2195 line-to-neutral; the 1 A
supply is *not* the binding constraint (it would allow ~1.38 V / 6.3 A), phase current is. Chosen
`kVoltageRunV = 0.30 V` -> ~1.4 A peak phase, ~0.6 W, ~50 mA from the bus (5% of the limit), duty
2.3%. Ramped from 0 at 0.5 V/s, never stepped, hard-capped at 0.5 V. Expected motion is **2.9-4.5
degrees at the output — mark the rotor bell or you will not see it. A twitch is success.**

Guards: 15 s armed-after-delay with LED countdown; pre-arm refuses unless bus 11.5-14.5 V, FET
5-45 C, servo stopped and fault-free; aborts latch de-energised on FET >55 C, |I| >4 A, bus <11 V
or >15.5 V, any moteus fault, or mode-timeout 500 ms. Budget: 5 loops / 34 s cumulative energised /
20 min uptime, whichever first. Config defaults tightened by the build define: `max_current_A 5`,
`max_power_W 20`, `max_voltage 18`, `fault_temperature 60`, `timeout_mode 0`, `drv8323.vds_lvl_mv
100` (~62 A trip; the inherited 700 mV was ~440 A, i.e. no protection at all).

Image 444,504 B, 10,152 B free. Telemetry struct `g_bench_telemetry` at `0x20000d68`, 26 words,
word 0 must read `b3ac0001`.

> Gotcha, 2026-09-07 02:20 IST: `max_current_A` / `max_power_W` are enforced by the **current
> controller**, which kVoltageFoc does not run. In this mode the only real protections are the
> 1 kHz software checks, the DRV VDS OCP, and the bench supply limit. Do not read those config
> values as safety.

> Gotcha, 2026-09-07 02:20 IST: **never `halt` while energised** — a halt freezes the PWM
> mid-vector with one phase pair held on. The `bench` telemetry mode reads RAM without halting;
> `benchhalt` and `diag` are only safe while the LED shows rest / done / fault.

> Gotcha, 2026-09-07 02:20 IST: this test does **not** validate the phase-order fix. Open-loop
> voltage FOC is indifferent to sense pairing, so "forward" is an arbitrary direction. It validates
> that the stage switches and produces torque, nothing more. The phase-order gate stays closed.

Known-good image preserved at `tools/bench/out-good/` (md5-verified against the ef0d948 build) so
the working firmware can always be restored.

Unvalidated at the time: `bus_V` against a DMM, the DRV8353 enable, and reading RAM without halting
via this ST-Link clone. All three were closed on 2026-09-07/08 — next entry.

## 2026-09-07 → 2026-09-08 — first spin (branch `bench/openloop-test`, `843566b` → `0e29bad`)

Recorded 2026-09-08 13:20 IST from the bench-branch commit messages and the STAGE CONSTANTS block of `flexnode_bench_openloop.cc`; the test images stay on the branch and `main` is unchanged. Motor GIM 8108-8 (8:1 output), no encoder, 13 V adapter whose current limit measured at 1.03 A. Open-loop `kVoltageFoc` through the stock `BldcServo::Command()` path — FOC / PWM / current-sense / gate-driver code untouched.

- First run (2026-09-07) aborted at the end of the countdown on a **false** overcurrent: the DRV8353 CSA outputs sit at 0 V while the driver sleeps and moteus calibrates offsets only after enable. Fix `8f28710`: current checks gated on `servo_mode == kVoltageFoc`, new `kSensorInvalid` class. Bus 12.4–12.5 V and FET 31.9 °C read correctly from boot.
- **DRV8353S enabled; the power stage switched; the motor turned.** Run 2 (0.30 V, 0.1 rev/s) moved the output 103/104° per movement as designed, 1,047 mA measured vs ~1.0 A modelled after the dead-time loss.
- **Phase-current sense validated**: all three offsets calibrate once the driver is enabled; phase currents sum to ~0 (the `kSensorInvalid` check depends on it). V–I points fit R ≈ 0.364 Ω/phase, V_dt ≈ 30 mV (honest range 0.33–0.44 Ω; the stage-1/2 predictions had halved the datasheet R — `40a25a6`).
- **Stage 2** (1.33 V / 0.8 rev/s, `9ef8d20`): **8 loops, 140 s energised, zero faults, FET plateau 38.7 °C.** Forward half-sine 4.5 s, reverse square 2.875 s.
- **Stage 3** (3.325 V / 2.0 rev/s, `40a25a6`) sag-aborted at the 1.8 V sweep step exactly as modelled (4.83 A, 12.9 W, 1.03 A; adapter collapsed 12.57 → 10.46 V). **The bus-sag abort works and de-energises cleanly.** Stage 3 waits for a bigger supply; stage 2R (`0e29bad`) rolls the drive back to stage-2 parameters.
- **`bus_V` vs DMM done** (over SWD telemetry, not CAN): DMM 12.82 V vs board 12.50 V (12.64 V running max) → ratio 1.0145–1.0255, midpoint applied: `vsense_adc_scale` 0.067944 → 0.069540 (bench branch only so far). The R30 rescale was right to ~2.5 %.
- V–I sweep segment (`7cc9617`, `0e29bad`): five aligned voltage steps per loop, least-squares R and V_dt with residuals, ΔR/R → winding ΔT at 0.393 %/K. Sensorless motor temperature, which the unpopulated NTC pad cannot provide.

Bench image 445,936 B; 8,720 B free.

**Not validated by any of this:** the phase-order fix (open-loop drive is indifferent to it — gate stays closed); anything closed-loop (AS5047 still unsoldered: no calibration, no position control has ever run); CAN (no adapter; the register block has never been read); servo output, 5 V rail sense, ToF; switching edges / EMI on the BSC016N06NS (not scoped).

## Still gated (as of 2026-09-08)
| Gate | Status | What unblocks it |
|---|---|---|
| CAN enumeration, telemetry, register block over the wire | not started | a CAN-FD adapter (fdcanusb or CANable-FD) |
| Encoder bring-up on PC6 | not started | AS5047 soldered to the back side |
| Config-write path (0x0807F000) survives power cycle | not started | `conf write` over CAN, then power cycle |
| **Phase-order validation** | not started — open-loop spin cannot test it | encoder + current-limited `moteus_tool --calibrate`, watch convergence and phase currents. **Hard gate before closed-loop drive.** |
| `vsense_adc_scale` trim onto `main` | on the bench branch only | port the one-line change from `0e29bad` |
| Bring-up config: `servo.max_current_A` 25–30, `servo.vds_lvl_mv` 100–200, `servo.max_voltage` ≈ 38 (8S) | not applied | CAN |
| Gate-drive edges / EMI for BSC016N06NS (inherited r4.11 currents) | drove ≤ 4.8 A without incident; edges not scoped | a scope on the first closed-loop spin |

## 2026-09-08 — first-spin telemetry, as read off the board

Recorded because these figures existed only in a session transcript and a report agent (correctly)
refused to publish them as unverifiable. All are direct reads of `g_bench_telemetry` over SWD
during the stage-2 run (bench branch, `19df39b`..`8f28710`), or arithmetic on those reads.

**Trajectory tracking.** At `seg_elapsed_ms 1957` of a 4,500 ms half-sine forward segment:
- `seg_rotor_mrev 913` x 0.045 = **41.09 deg at the output**; the half-sine integral predicts
  103 x (1 - cos(pi x 1957/4500))/2 = **41.0 deg**.
- `cmd_rate_mrad_s 103,356` against a predicted 105,600 x sin(pi x 1957/4500) = **103,382**
  (0.025 % error). An earlier sample: 336 measured vs 335 predicted at 291 ms.

**Phase-current balance** (validates all three sense channels and the phase wiring together, since
a star winding must sum to zero): `3142 / -2819 / -241 mA` -> sum **82 mA** against ~3,000 mA
magnitudes. A second sample `2416 / -2739 / 483` -> 160 mA. At align, `644 / -241 / -402` -> **1 mA**.

**Current-sense offsets** calibrate off the 2048 default to 2012-2050 and drift only a couple of
LSB with temperature.

**Thermal.** FET sensor 31.9 C idle -> plateau 37.3-38.7 C after ~140 s energised; **cold-start
read 29.17 C at 4 s from power-up against 28 C ambient** (two independent references on a nearby
3D printer), which is what settles the thermistor question below.

**Endurance.** 8 loops, ~140 s energised, `abort_reason 0`, `servo_fault 0`, `drv_bits 0` throughout.

> Gotcha, 2026-09-08: the very first energisation attempt **aborted on a false overcurrent** — the
> DRV8353's current-sense amps output 0 V while the driver sleeps, so with the default 2048 offset
> all three phases read a rail of **-164,999 mA** ((0 - 2048) x 80.57 mA), and the abort check was
> evaluated before the drive chain was ready. Fixed by gating current checks on `servo_mode == 7`.
> So "the gate driver came up" is true; "worked on the first attempt" is **not** a claim to publish.

### Thermistor question — CLOSED 2026-09-08
The FET thermistor is honest. A cold-start read of **29.17 C at 4 s** against 28 C ambient leaves no
room for a meaningful offset; the 31-32 C seen "at rest" in earlier runs was genuine buck and MCU
self-heating, as Aditya proposed. **No calibration change needed.** The motor NTC is a separate
matter — the pad is unpopulated (`motor_ntc_raw` reads 10-15, i.e. nothing) and needs a part fitted
before it can be calibrated; `motor_thermistor_ohm` is config, so no rebuild will be required.

### Still open from this run
- `vsense_adc_scale` 0.067944 -> **0.069540** exists **only on `bench/openloop-test`**. Main still
  carries the old value. Port it once confirmed with three simultaneous DMM/board readings at rest.
- The V-I sweep's phase-resistance fit **failed all five acceptance criteria** (R 295,122 uOhm
  outside the 330k-440k window, rms residual 149 mA, max 249 mA, imbalance 805 mA, V_dt 312 mV).
  Cause: the rotor moves during the sweep — gearbox backlash plus almost no damping, re-excited by
  each voltage step. Incremental slopes still cluster at **0.37-0.42 Ohm** and **0.2195 Ohm is
  definitively excluded**. Fix: clamp the output shaft mechanically, and replace the stepped sweep
  with a slow continuous voltage ramp plus per-sample motion rejection.

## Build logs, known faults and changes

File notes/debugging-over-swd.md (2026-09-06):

# Debugging over SWD

No CAN adapter yet, so SWD is the only window into the running firmware. These are the moves that worked on 2026-09-06.

## Toolkit (all in `flexnode-swd.ps1`)
- **`probe`**: link sanity. If it prints the chip ID, the wiring is good. First thing after touching the harness.
- **`diag`**: halts and prints PC ten times over ~2 s. Varied addresses across the app (0x0803…–0x0806…), some in `Handler PendSV`, some in CCM RAM (0x1000…, the control ISR) = healthy main loop. Ten identical addresses = stuck there; map the address with `arm-none-eabi-addr2line -e moteus.elf <addr>`.
- **Read live variables by symbol.** For anything that isn't a global (most of the moteus object graph is pool-allocated), add a temporary namespace-scope `volatile uint32_t g_xxx_dbg[N]` in the relevant `.cc`, fill it each poll, build, then:
  ```
  arm-none-eabi-nm moteus.elf | grep xxx_dbg      # → 20000d60 B _ZN6moteus9g_led_dbgE
  ```
  and add a one-off script mode that does `halt; mdw 0x20000d60 N; resume`, twice with a `sleep` between, so you see what moves. Strip the array before committing. This is what finally cracked the LED (see [`ws2812-led.md`](ws2812-led.md)).
- Toolchain binaries live in the Bazel external tree: `moteus-r4-parent/bazel-moteus-r4-parent/external/com_arm_developer_gcc/bin/arm-none-eabi-{nm,objdump,readelf,addr2line,gdb}`. Call them from a script file, not an inline `wsl.exe bash -c`.

## What openocd errors actually meant here
| Message | Meant |
|---|---|
| `init mode failed (unable to connect to the target)` | SWD signal path broken: a wire off, DIO/CLK swapped or shifted, marginal GND, or NRST pulled while the ST-Link was powered. Board keeps running; the LED stays lit. Fix wiring, then `probe`. |
| `Fail reading CTRL/STAT register. Force reconnect` mid-program, then `Programming Failed` | Link dropped during the write. Every time it was physical: power pulled, or the board handled. App region now partial. Reseat, `probe`, reflash. |
| `couldn't bind gdb to socket on port 3333` | Stale openocd process, or another program on 3333. The script now disables that port. |
| `target was in unknown state when halt was requested` | Normal on a running target. Ignore. |
| `Target voltage: 2.3` | ST-Link's floating VTref pin. Ignore. |
| `Unable to match requested speed 2000 kHz, using 1800 kHz` | Normal for the clone. Ignore. |

## Reasoning traps this session fell into
Recorded because each one cost real time.
1. **"Steady colour" ≠ "static image".** An LED holding a colour after a reflash looked like the reset not taking. It was the WS2812 never receiving a valid off frame. Before blaming the reset path, check whether the firmware *thinks* it has sent something different from what you see.
2. **Don't assume a dark LED means a stopped MCU.** The NRST-hold made the board dark while perfectly fine. Separate "is it powered/running" (diag, probe) from "is the LED being driven correctly".
3. **Correlation with the debugger is ambiguous.** "Works only with the ST-Link plugged in" can be DWT (debug-only counter), NRST (unpowered ST-Link holds reset), or 3V3 back-power. Test them one at a time; here it was NRST, and the DWT theory was wrong.
4. **Verify passed ≠ the behaviour you're watching is new.** It was, every time; the *display* was stale, not the image. But do check `ms` uptime in a symbol read to be sure a fresh boot happened.

<!-- self: reading `status_.frames` and `want[0]` side by side was the decisive pair: "wants 0, frames stopped, LED still lit" isolated the transmit/physical layer from the render logic in one read. Reach for that shape of diagnostic early next time. -->

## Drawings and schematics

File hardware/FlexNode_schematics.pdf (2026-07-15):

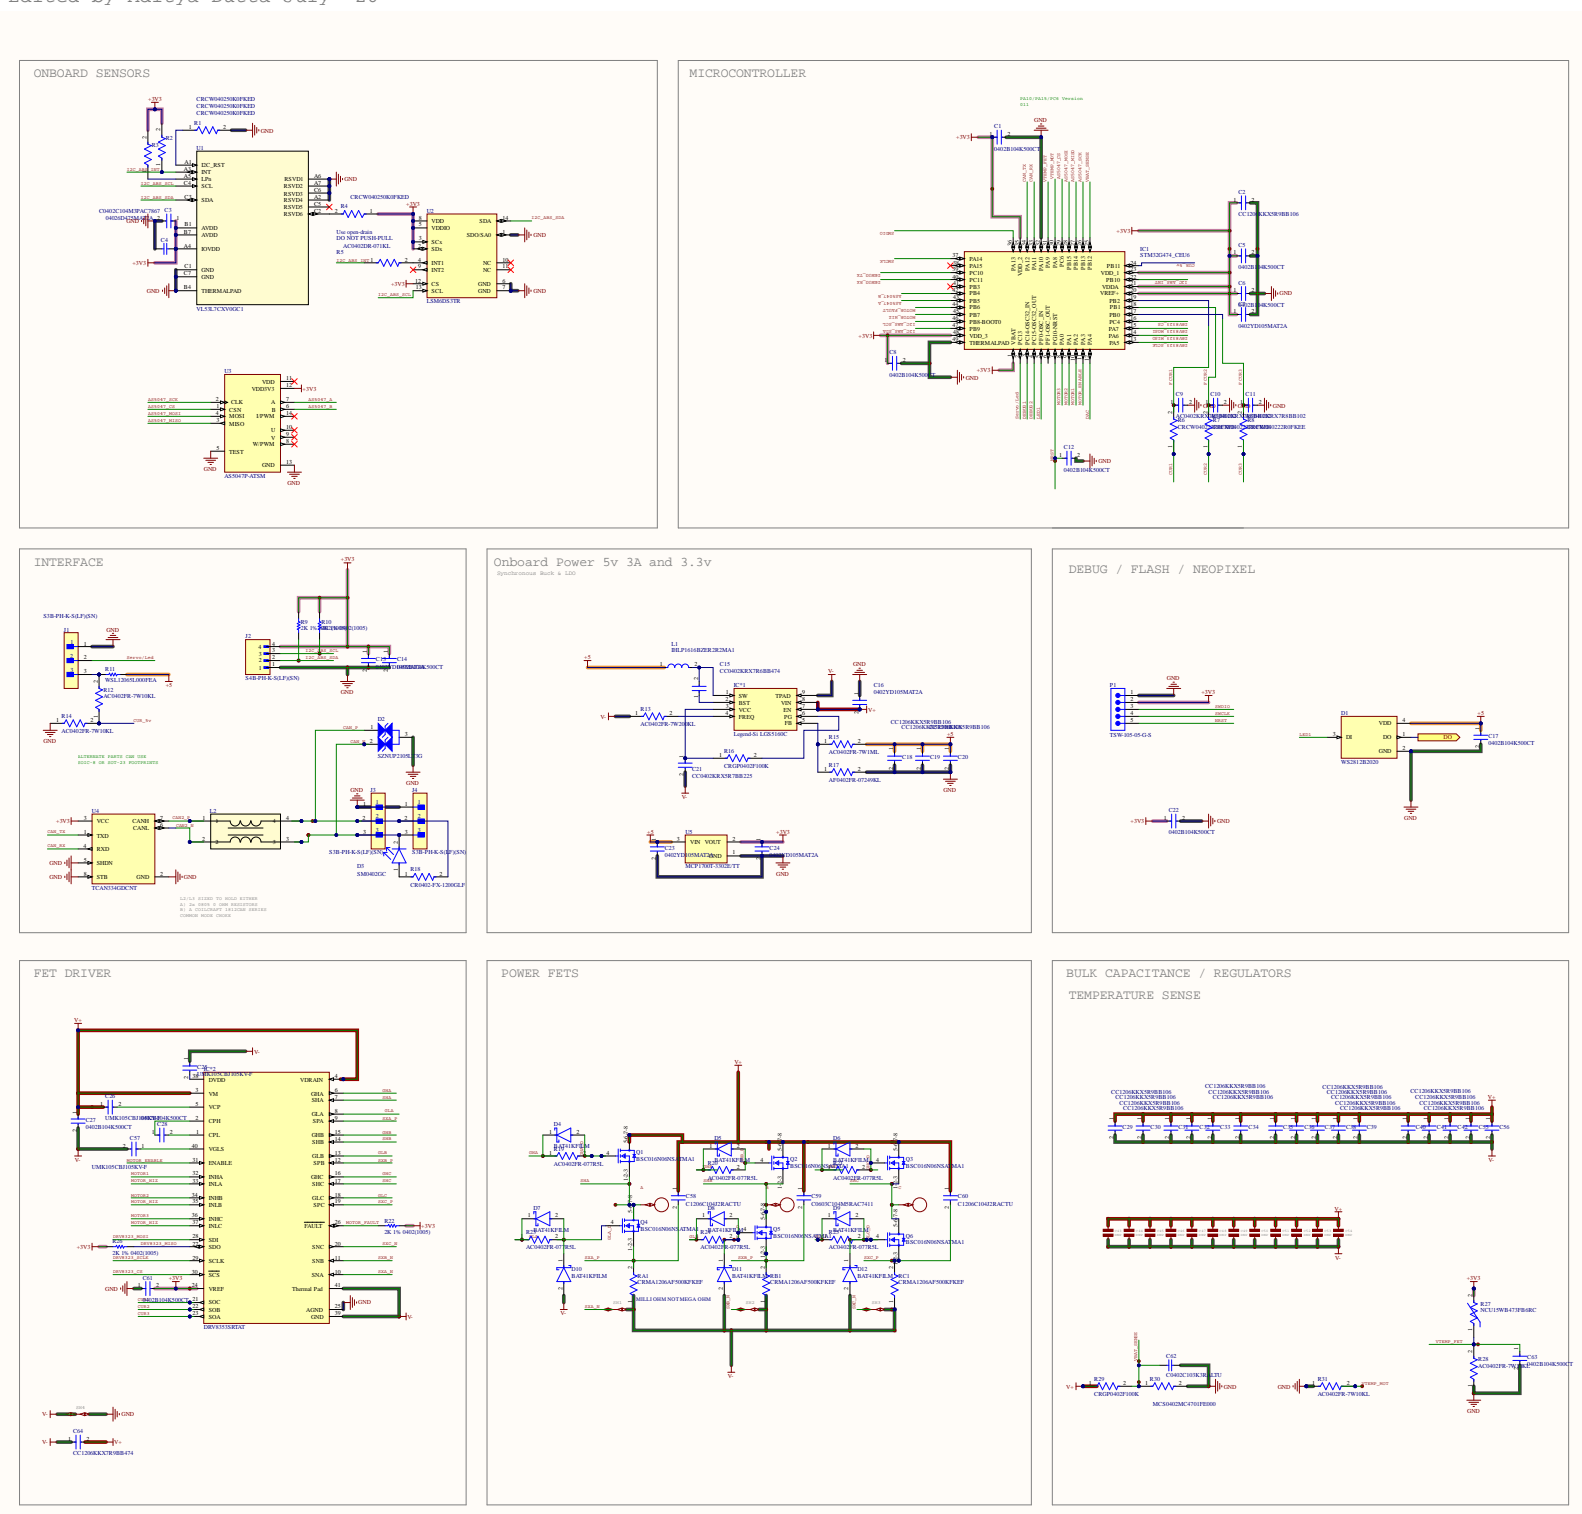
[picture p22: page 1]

Edited by Aditya Dutta July '26

DEBUG / FLASH / NEOPIXEL INTERFACE

5 NRST C22 | DI 3 DO | 1 DO

ALTERNATE PARTS CAN USE
SOIC-8 OR SOT-23 FOOTPRINTS

L2/L3 SIZED TO HOLD EITHER
A) 2x 0805 0 OHM RESISTORS
B) A COILCRAFT 1812CAN SERIES
COMMON MODE CHOKE

MILLI OHM NOT MEGA OHM

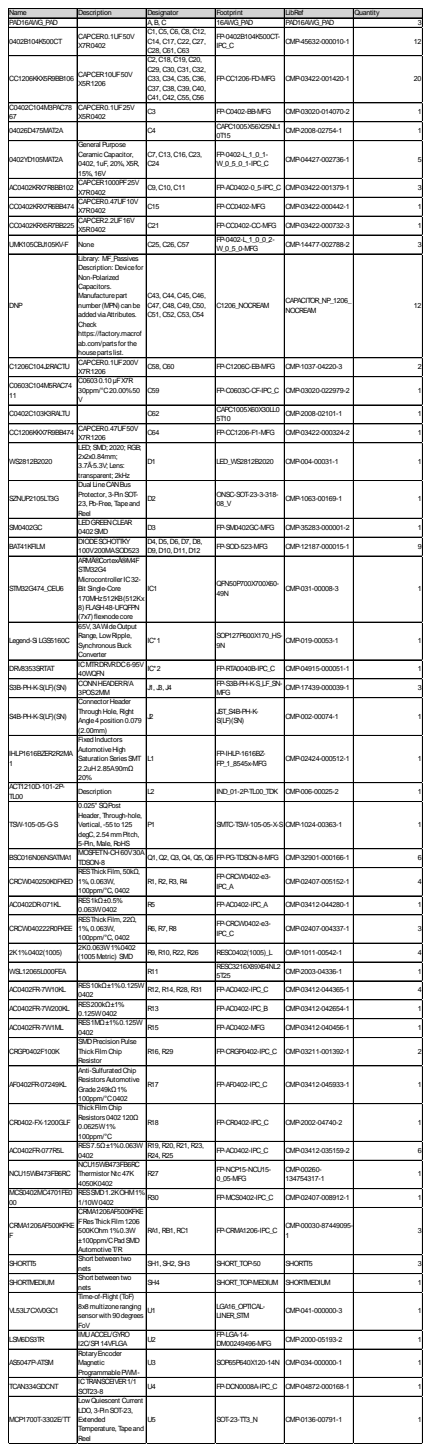
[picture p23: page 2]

0402B104K500CT | CAPCER0.1UF50V X7R0402 | C1, C5, C6, C8, C12, C14, C17, C22, C27, C28, C61, C63 | FP-0402B104K500CT-IPC_C | CMP-45632-000010-1 | 12

CC1206KKX5R9BB106 | CAPCER10UF50V X5R1206 | C2, C18, C19, C20, C29, C30, C31, C32, C33, C34, C35, C36, C37, C38, C39, C40, C41, C42, C55, C56 | FP-CC1206-FD-MFG | CMP-03422-001420-1 | 20

C0402C104M3PAC78 67 | CAPCER0.1UF25V X5R0402 | C3 | FP-C0402-BB-MFG | CMP-03020-014070-2 | 1

04026D475MAT2A | | C4 | CAPC1005X56X25NL1 0T15 | CMP-2008-02754-1 | 1

0402YD105MAT2A | General Purpose Ceramic Capacitor, 0402, 1uF, 20%, X5R, 15%, 16V | C7, C13, C16, C23, C24 | FP-0402-L_1_0_1-W_0_5_0_1-IPC_C | CMP-04427-002736-1 | 5

AC0402KRX7R8BB102 | CAPCER1000PF25V X7R0402 | C9, C10, C11 | FP-AC0402-0_5-IPC_C | CMP-03422-001379-1 | 3

CC0402KRX7R6BB474 | CAPCER0.47UF10V X7R0402 | C15 | FP-CC0402-MFG | CMP-03422-000442-1 | 1

CC0402KRX5R7BB225 | CAPCER2.2UF16V X5R0402 | C21 | FP-CC0402-CC-MFG | CMP-03422-000732-3 | 1

UMK105CBJ105KV-F | None | C25, C26, C57 | FP-0402-L_1_0_0_2-W_0_5_0-MFG | CMP-14477-002788-2 | 3

DNP | Library: MF_Passives Description: Devicefor Non-Polarized Capacitors. Manufacturepart number(MPN) canbe addedviaAttributes. Check https://factory.macrofab.com/partsforthe housepartslist. | C43, C44, C45, C46, C47, C48, C49, C50, C51, C52, C53, C54 | C1206_NOCREAM | CAPACITOR_NP_1206_ NOCREAM | 12

C1206C104J2RACTU | CAPCER0.1UF200V X7R1206 | C58, C60 | FP-C1206C-EB-MFG | CMP-1037-04220-3 | 2

C0603C104M5RAC74 11 | C06030.10μFX7R 30ppm/°C20.00%50 V | C59 | FP-C0603C-CF-IPC_C | CMP-03020-022979-2 | 1

C0402C103K3RALTU | | C62 | CAPC1005X60X30LL0 5T10 | CMP-2008-02101-1 | 1

CC1206KKX7R9BB474 | CAPCER0.47UF50V X7R1206 | C64 | FP-CC1206-F1-MFG | CMP-03422-000324-2 | 1

WS2812B2020 | LED; SMD; 2020; RGB; 2x2x0.84mm; 3.7Ã·5.3V; Lens: transparent; 2kHz | D1 | LED_WS2812B2020 | CMP-004-00031-1 | 1

SZNUP2105LT3G | Dual LineCANBus Protector, 3-PinSOT-23, Pb-Free, Tapeand Reel | D2 | ONSC-SOT-23-3-318-08_V | CMP-1063-00169-1 | 1

SM0402GC | LEDGREENCLEAR 0402SMD | D3 | FP-SM0402GC-MFG | CMP-35283-000001-2 | 1

BAT41KFILM | DIODESCHOTTKY 100V200MASOD523 | D4, D5, D6, D7, D8, D9, D10, D11, D12 | FP-SOD-523-MFG | CMP-12187-000015-1 | 9

STM32G474_CEU6 | ARMÂ®CortexÂ®-M4F STM32G4 MicrocontrollerIC32-Bit Single-Core 170MHz512KB(512Kx 8)FLASH48-UFQFPN (7x7)flexnodecore | IC1 | QFN50P700X700X60-49N | CMP-031-00008-3 | 1

Legend-Si LGS5160C | 65V, 3AWideOutput Range, LowRipple, SynchronousBuck Converter | IC*1 | SOP127P600X170_HS-9N | CMP-019-00053-1 | 1

DRV8353SRTAT | ICMTRDRVRDC6-95V 40WQFN | IC*2 | FP-RTA0040B-IPC_C | CMP-04915-000051-1 | 1

S3B-PH-K-S(LF)(SN) | CONNHEADERR/A 3POS2MM | J1, J3, J4 | FP-S3B-PH-K-S_LF_SN-MFG | CMP-17439-000039-1 | 3

S4B-PH-K-S(LF)(SN) | Connector Header ThroughHole, Right Angle4position0.079 (2.00mm) | J2 | JST_S4B-PH-K-S(LF)(SN) | CMP-002-00074-1 | 1

IHLP1616BZER2R2MA 1 | FixedInductors AutomotiveHigh SaturationSeriesSMT 2.2uH2.85A90mΩ 20% | L1 | FP-IHLP-1616BZ-FP_1_8545x-MFG | CMP-02424-000512-1 | 1

ACT1210D-101-2P-TL00 | Description | L2 | IND_01-2P-TL00_TDK | CMP-006-00025-2 | 1

TSW-105-05-G-S | 0.025"SQPost Header, Through-hole, Vertical, -55to125 degC, 2.54mmPitch, 5-Pin, Male, RoHS | P1 | SMTC-TSW-105-05-X-S | CMP-1024-00363-1 | 1

BSC016N06NSATMA1 | MOSFETN-CH60V30A TDSON-8 | Q1, Q2, Q3, Q4, Q5, Q6 | FP-PG-TDSON-8-MFG | CMP-32901-000166-1 | 6

CRCW040250K0FKED | RESThickFilm, 50kΩ, 1%, 0.063W, 100ppm/°C, 0402 | R1, R2, R3, R4 | FP-CRCW0402-e3-IPC_A | CMP-02407-005152-1 | 4

AC0402DR-071KL | RES1kΩ±0.5% 0.063W0402 | R5 | FP-AC0402-IPC_A | CMP-03412-044280-1 | 1

CRCW040222R0FKEE | RESThickFilm, 22Ω, 1%, 0.063W, 100ppm/°C, 0402 | R6, R7, R8 | FP-CRCW0402-e3-IPC_C | CMP-02407-004337-1 | 3

2K1%0402(1005) | 2K0.063W1%0402 (1005Metric) SMD | R9, R10, R22, R26 | RESC0402(1005)_L | CMP-1011-00542-1 | 4

WSL12065L000FEA | | R11 | RESC3216X89X64NL2 5T25 | CMP-2003-04336-1 | 1

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

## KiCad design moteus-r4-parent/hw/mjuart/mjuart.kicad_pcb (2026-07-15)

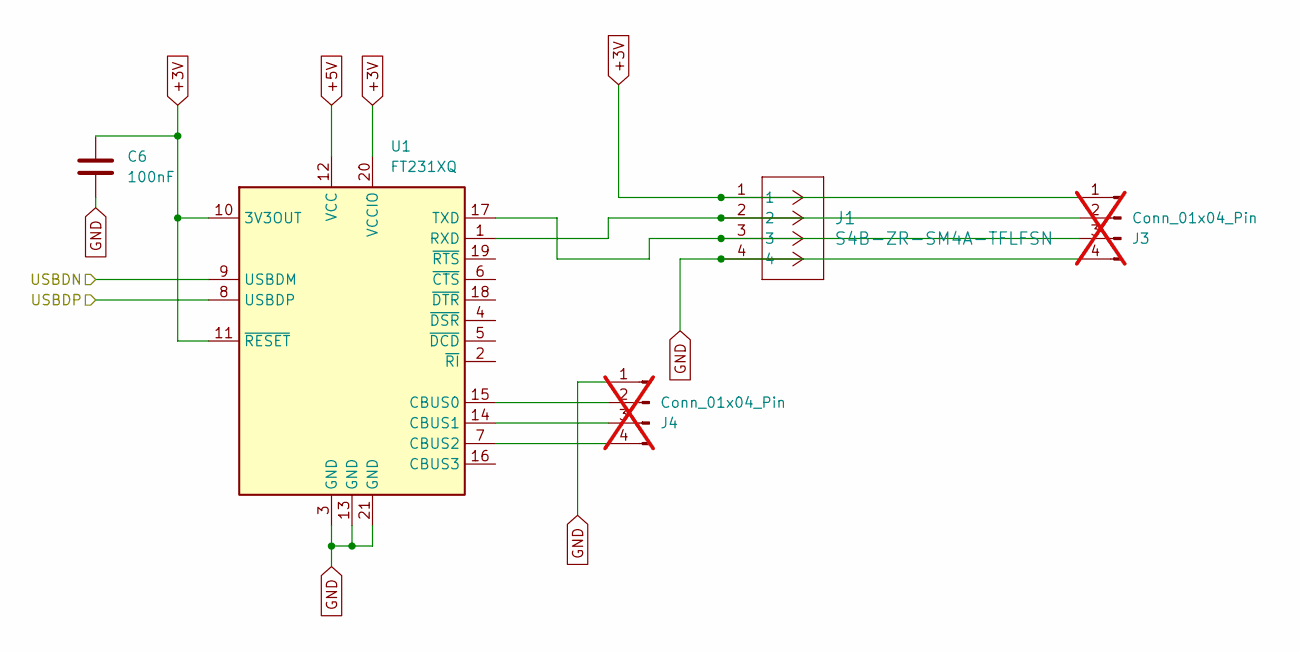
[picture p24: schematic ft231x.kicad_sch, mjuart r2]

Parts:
C6: 100nF; C_0603_1608Metric; MPN MF-CAP-0603-0.1uF
J1: S4B-ZR-SM4A-TFLFSN; CONN_S4B-ZR-SM4A-TF_JST; MPN S4B-ZR-SM4A-TF(LF)(SN)
J3, J4: Conn_01x04_Pin; testpad4; not fitted
U1: FT231XQ; QFN-20-1EP_4x4mm_P0.5mm_EP2.5x2.5mm; MPN FT231XQ-T

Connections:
+3V: C6.1, J1.1, J3.1, U1.10 (3V3OUT), U1.11 (~RESET), U1.20 (VCCIO)
+5V: U1.12 (VCC); also elsewhere on the board
/Power Input/USBDN: U1.9 (USBDM); also elsewhere on the board
/Power Input/USBDP: U1.8 (USBDP); also elsewhere on the board
GND: C6.2, J1.4, J3.4, J4.1, U1.3 (GND), U1.13 (GND), U1.21 (GND); also elsewhere on the board
unnamed: J1.2, J3.2, U1.1 (RXD)
unnamed: J1.3, J3.3, U1.17 (TXD)
unnamed: J4.2, U1.15 (CBUS0)
unnamed: J4.3, U1.14 (CBUS1)
unnamed: J4.4, U1.7 (CBUS2)

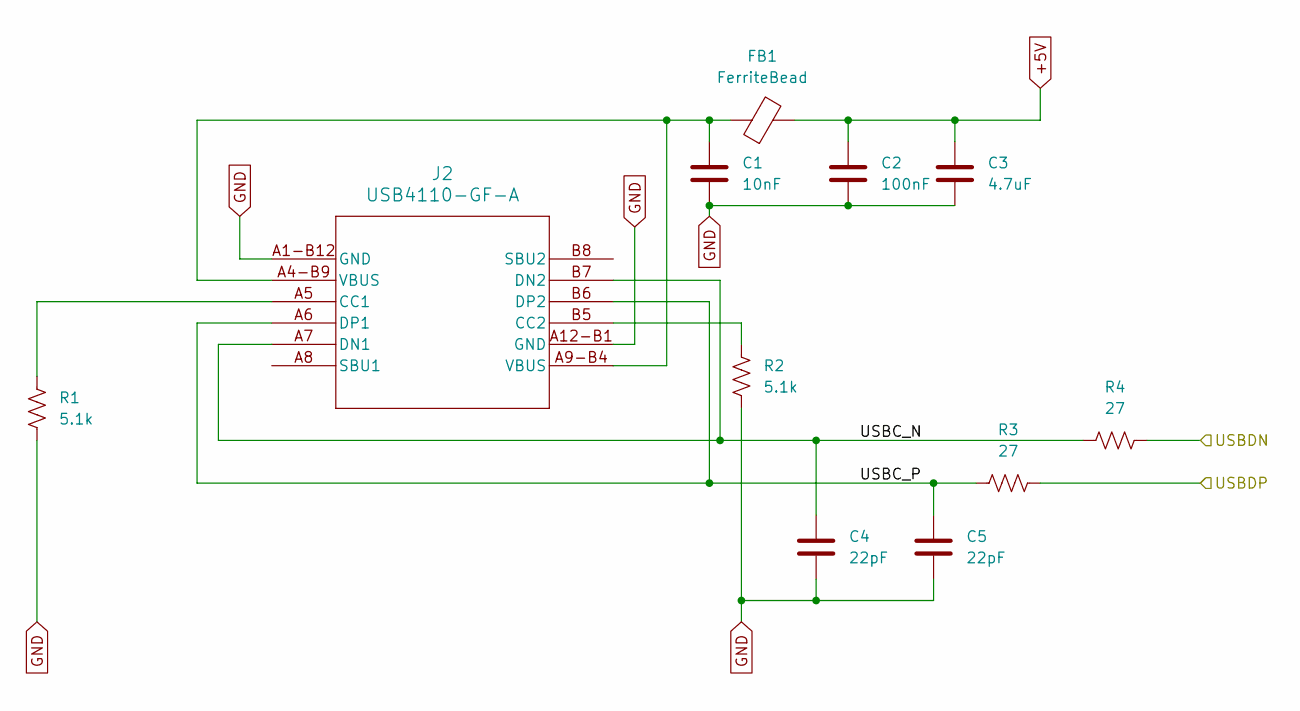
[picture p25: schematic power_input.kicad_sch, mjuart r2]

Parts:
C1: 10nF; C_0603_1608Metric; MPN MF-CAP-0603-0.01uF
C2: 100nF; C_0603_1608Metric; MPN MF-CAP-0603-0.1uF
C3: 4.7uF; C_0603_1608Metric; MPN GRT188C81E475KE13D
C4, C5: 22pF; C_0603_1608Metric; MPN MF-CAP-0603-22pF
FB1: FerriteBead; FB_MI0805K400R-10; MPN MI0805K400R-10
J2: USB4110-GF-A; USB4110-GF-A_GCT; MPN USB4110-GF-A
R1, R2: 5.1k; R_0603_1608Metric; MPN RC0603FR-075K1L
R3, R4: 27; R_0603_1608Metric; MPN MF-RES-0603-27

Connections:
+5V: C2.1, C3.1, FB1.2; also elsewhere on the board
/Power Input/USBC_N: C4.1, J2.A7 (DN1), J2.B7 (DN2), R4.1
/Power Input/USBC_P: C5.1, J2.A6 (DP1), J2.B6 (DP2), R3.1
/Power Input/USBDN: R4.2; also elsewhere on the board
/Power Input/USBDP: R3.2; also elsewhere on the board
GND: C1.2, C2.2, C3.2, C4.2, C5.2, J2.A1-B12 (GND), J2.A12-B1 (GND), R1.2, R2.2; also elsewhere on the board
unnamed: C1.1, FB1.1, J2.A4-B9 (VBUS), J2.A9-B4 (VBUS)
unnamed: J2.A5 (CC1), R1.1
unnamed: J2.B5 (CC2), R2.1

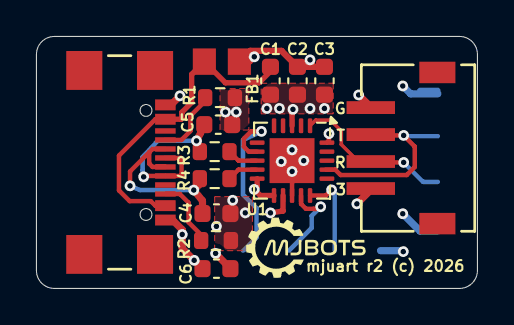
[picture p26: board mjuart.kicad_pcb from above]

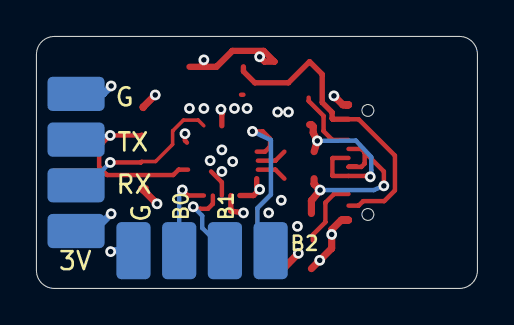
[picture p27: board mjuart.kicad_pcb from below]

Board: 4 copper layers, 24.5 x 14.0 mm, 16 parts (2 on the bottom side), 15 nets.

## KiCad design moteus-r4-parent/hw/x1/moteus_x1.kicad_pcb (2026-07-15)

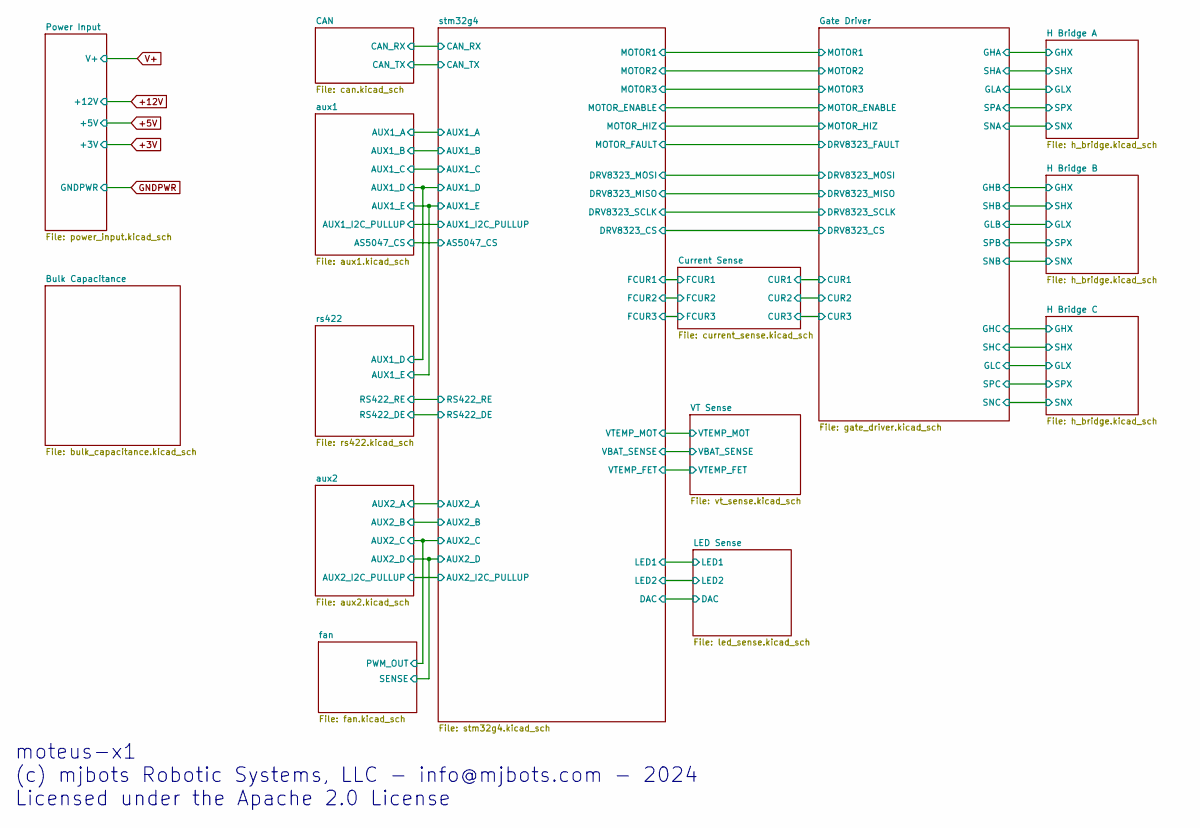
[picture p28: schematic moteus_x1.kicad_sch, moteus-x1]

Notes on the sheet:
moteus-x1 (c) mjbots Robotic Systems, LLC - info@mjbots.com - 2024 Licensed under the Apache 2.0 License

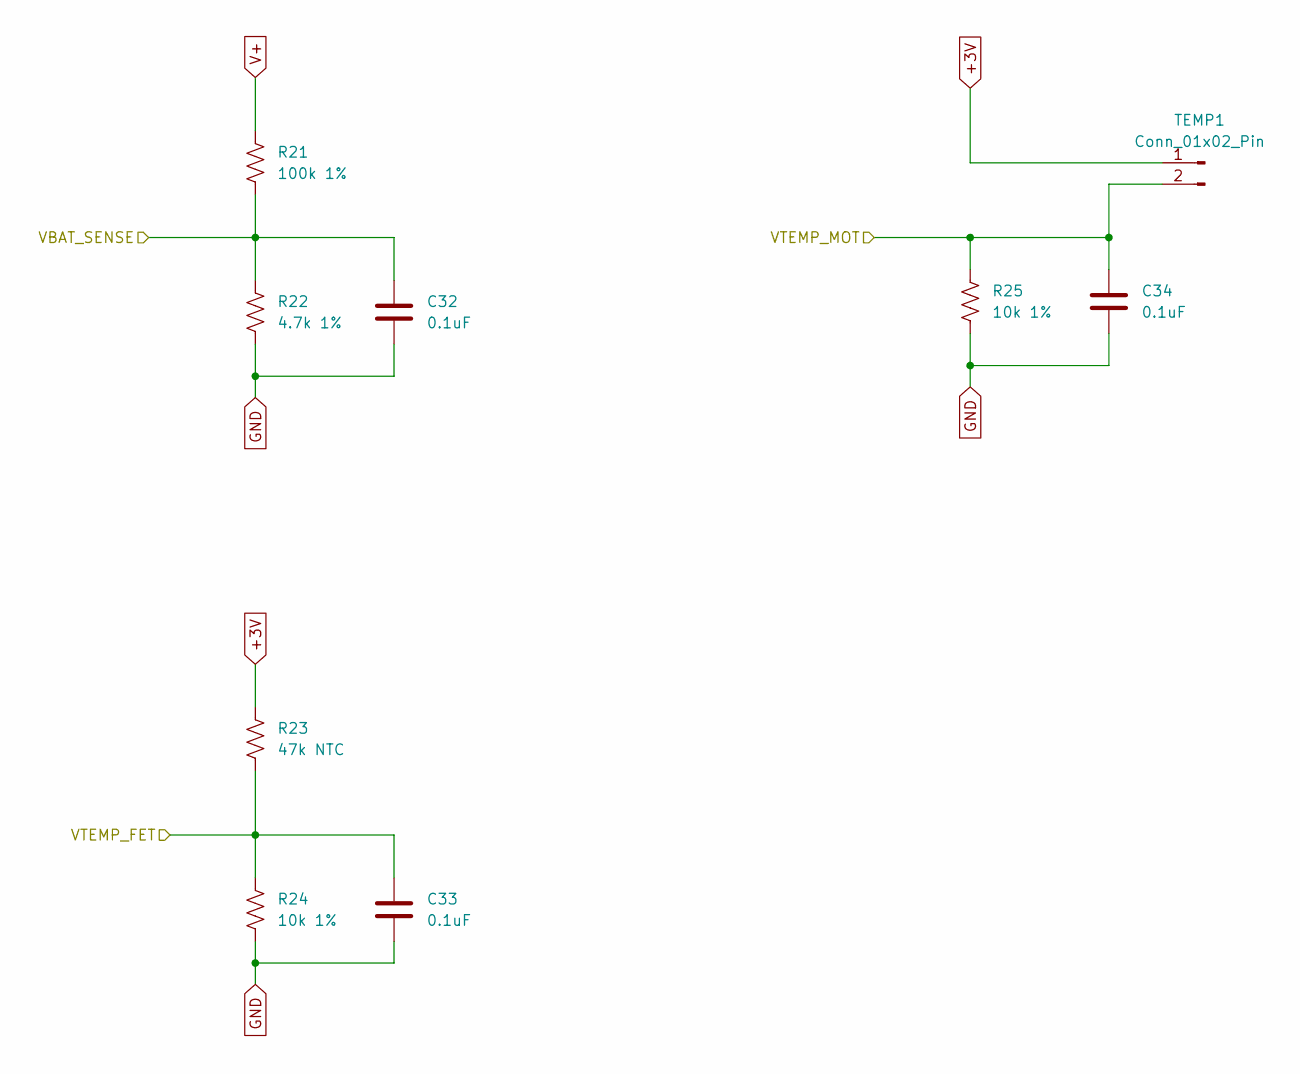
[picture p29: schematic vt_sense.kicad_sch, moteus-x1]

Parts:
C32, C33, C34: 0.1uF; C_0402_1005Metric; MPN MF-CAP-0402-0.1uF
R21: 100k 1%; R_0402_1005Metric; MPN RC0402FR-07100KL
R22: 4.7k 1%; R_0402_1005Metric; MPN RC0402FR-074K7L
R23: 47k NTC; R_0402_1005Metric; MPN NCP15WB473F03RC
R24, R25: 10k 1%; R_0402_1005Metric; MPN RC0402FR-0710KL
TEMP1: Conn_01x02_Pin; PinHeader_1x02_P2.54mm_Vertical

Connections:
+3V: R23.1, TEMP1.1; also elsewhere on the board
/VT Sense/VBAT_SENSE: C32.1, R21.2, R22.1; also elsewhere on the board
/VT Sense/VTEMP_FET: C33.1, R23.2, R24.1; also elsewhere on the board
/VT Sense/VTEMP_MOT: C34.1, R25.1, TEMP1.2; also elsewhere on the board
GND: C32.2, C33.2, C34.2, R22.2, R24.2, R25.2; also elsewhere on the board
V+: R21.1; also elsewhere on the board

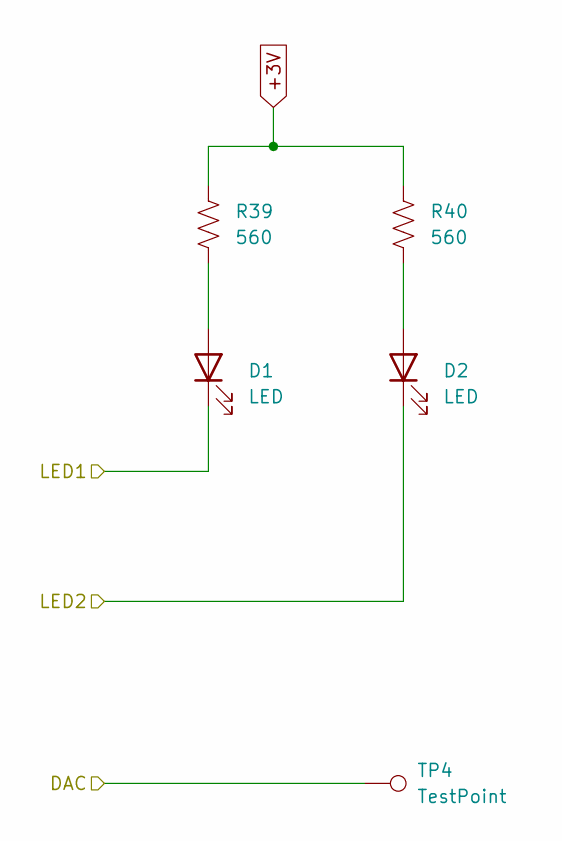
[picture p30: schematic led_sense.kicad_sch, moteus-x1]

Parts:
D1: LED; LED_0603_1608Metric; MPN MF-LED-0603-RED
D2: LED; LED_0603_1608Metric; MPN MF-LED-0603-GREEN
R39, R40: 560; R_0402_1005Metric; MPN MF-RES-0402-560
TP4: TestPoint; TestPoint_THTPad_D1.0mm_Drill0.5mm

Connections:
+3V: R39.1, R40.1; also elsewhere on the board
/LED Sense/DAC: TP4.1; also elsewhere on the board
/LED Sense/LED1: D1.1 (K); also elsewhere on the board
/LED Sense/LED2: D2.1 (K); also elsewhere on the board
unnamed: D1.2 (A), R39.2
unnamed: D2.2 (A), R40.2

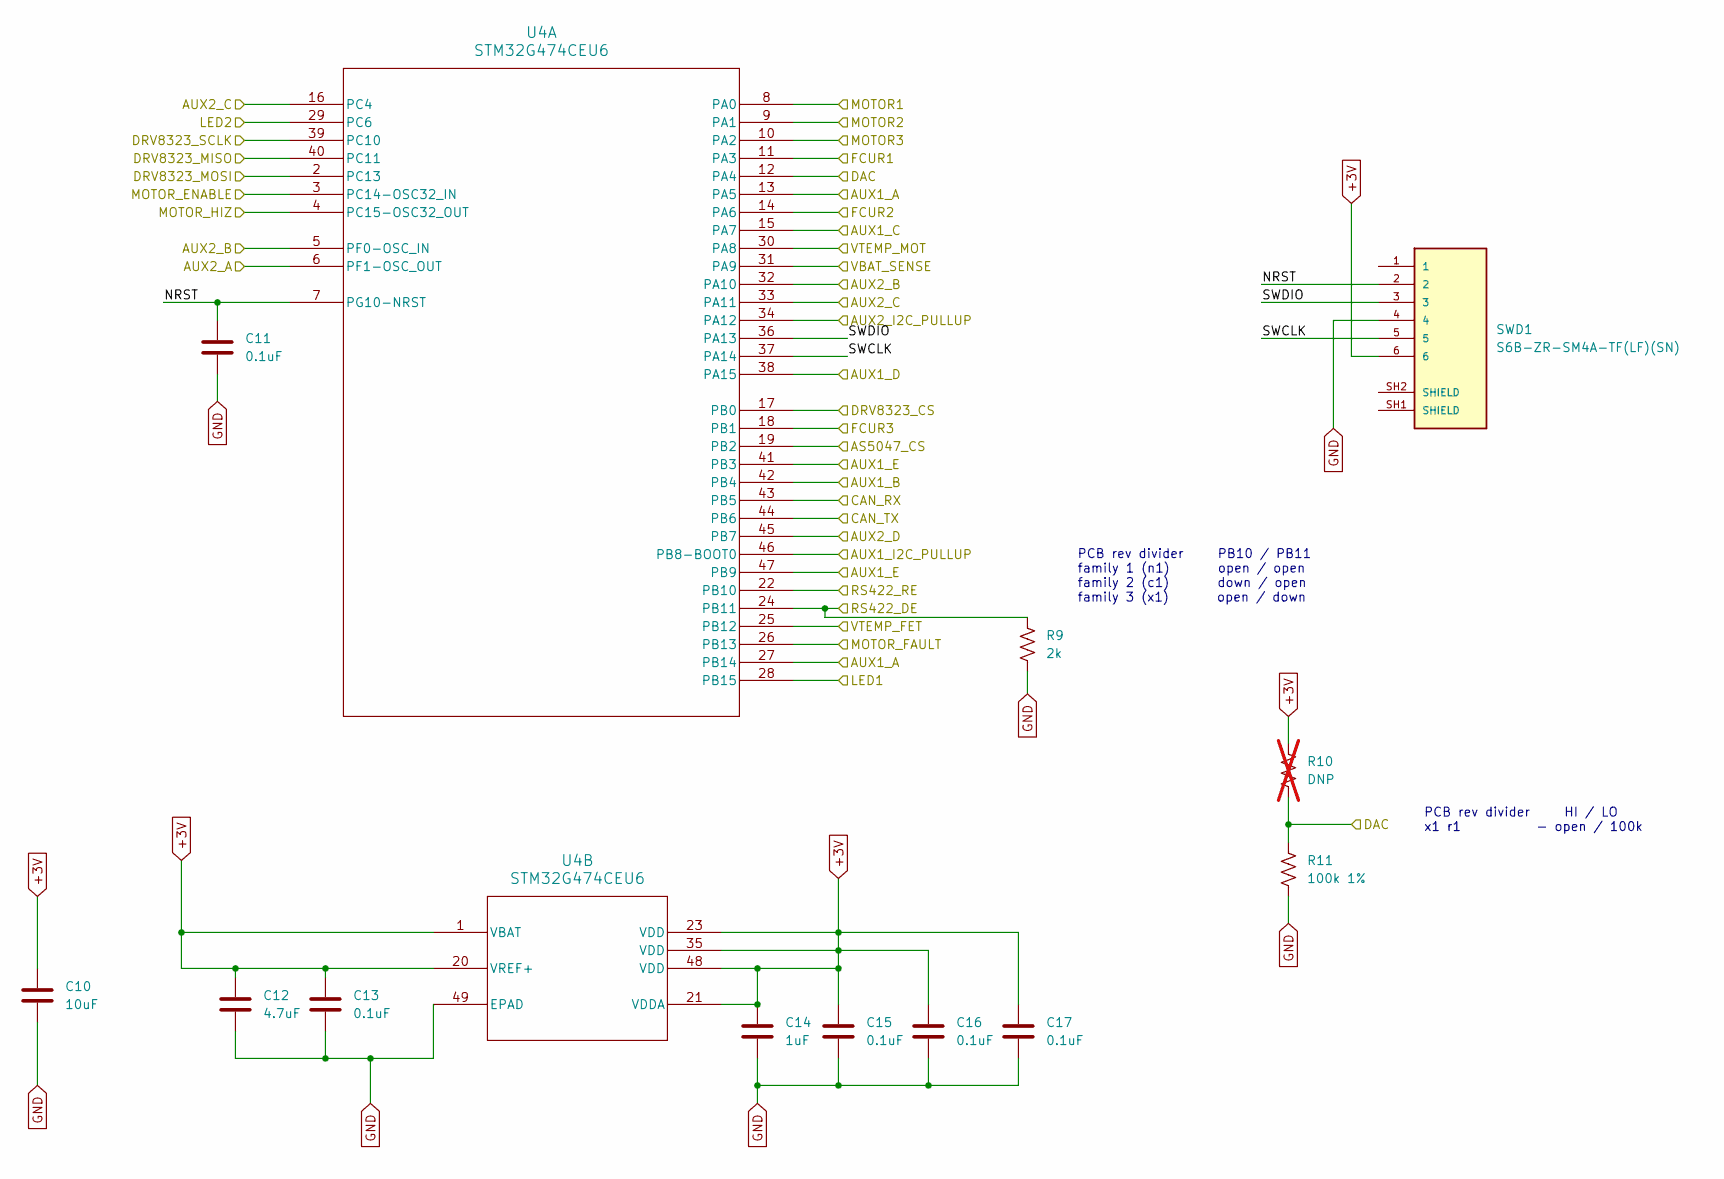
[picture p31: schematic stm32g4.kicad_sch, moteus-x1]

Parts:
C10: 10uF; C_1206_3216Metric; MPN MF-CAP-1206-10uF
C11, C13, C15, C16, C17: 0.1uF; C_0402_1005Metric; MPN MF-CAP-0402-0.1uF
C12: 4.7uF; C_0603_1608Metric; MPN CL10A475KP8NNNC
C14: 1uF; C_0402_1005Metric; MPN MF-CAP-0402-1uF
R9: 2k; R_0402_1005Metric; MPN MF-RES-0402-2K
R10: DNP; R_0402_1005Metric; not fitted
R11: 100k 1%; R_0402_1005Metric; MPN RC0402FR-07100KL
SWD1: S6B-ZR-SM4A-TF(LF)(SN); JST_S6B-ZR-SM4A-TF(LF)(SN); MPN S6B-ZR-SM4A-TF(LF)(SN)
U4: STM32G474CEU6; UFQFPN-48_7X7X0P55MM; MPN STM32G474CEU6

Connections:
+3V: C10.1, C12.1, C13.1, C14.1, C15.1, C16.1, C17.1, R10.1, SWD1.6, U4.1 (VBAT), U4.20 (VREF+), U4.21 (VDDA), U4.23 (VDD), U4.35 (VDD), U4.48 (VDD); also elsewhere on the board
/CAN/CAN_RX: U4.43 (PB5); also elsewhere on the board
/CAN/CAN_TX: U4.44 (PB6); also elsewhere on the board
/Current Sense/FCUR1: U4.11 (PA3); also elsewhere on the board
/Current Sense/FCUR2: U4.14 (PA6); also elsewhere on the board
/Current Sense/FCUR3: U4.18 (PB1); also elsewhere on the board
/Gate Driver/DRV8323_CS: U4.17 (PB0); also elsewhere on the board
/Gate Driver/DRV8323_FAULT: U4.26 (PB13); also elsewhere on the board
/Gate Driver/DRV8323_MISO: U4.40 (PC11); also elsewhere on the board
/Gate Driver/DRV8323_MOSI: U4.2 (PC13); also elsewhere on the board
/Gate Driver/DRV8323_SCLK: U4.39 (PC10); also elsewhere on the board
/Gate Driver/MOTOR1: U4.8 (PA0); also elsewhere on the board
/Gate Driver/MOTOR2: U4.9 (PA1); also elsewhere on the board
/Gate Driver/MOTOR3: U4.10 (PA2); also elsewhere on the board
/Gate Driver/MOTOR_ENABLE: U4.3 (PC14-OSC32_IN); also elsewhere on the board
/Gate Driver/MOTOR_HIZ: U4.4 (PC15-OSC32_OUT); also elsewhere on the board
/LED Sense/DAC: R10.2, R11.1, U4.12 (PA4); also elsewhere on the board
/LED Sense/LED1: U4.28 (PB15); also elsewhere on the board
/LED Sense/LED2: U4.29 (PC6); also elsewhere on the board
/VT Sense/VBAT_SENSE: U4.31 (PA9); also elsewhere on the board
/VT Sense/VTEMP_FET: U4.25 (PB12); also elsewhere on the board
/VT Sense/VTEMP_MOT: U4.30 (PA8); also elsewhere on the board
/aux1/AS5047_CS: U4.19 (PB2); also elsewhere on the board
/aux1/AUX1_A: U4.13 (PA5), U4.27 (PB14); also elsewhere on the board
/aux1/AUX1_B: U4.42 (PB4); also elsewhere on the board
/aux1/AUX1_C: U4.15 (PA7); also elsewhere on the board
/aux1/AUX1_D: U4.38 (PA15); also elsewhere on the board
/aux1/AUX1_E: U4.41 (PB3), U4.47 (PB9); also elsewhere on the board
/aux1/AUX1_I2C_PULLUP: U4.46 (PB8-BOOT0); also elsewhere on the board
/aux2/AUX2_A: U4.6 (PF1-OSC_OUT); also elsewhere on the board
/aux2/AUX2_B: U4.5 (PF0-OSC_IN), U4.32 (PA10); also elsewhere on the board
/aux2/AUX2_C: U4.16 (PC4), U4.33 (PA11); also elsewhere on the board
/aux2/AUX2_D: U4.45 (PB7); also elsewhere on the board
/aux2/AUX2_I2C_PULLUP: U4.34 (PA12); also elsewhere on the board
/rs422/RS422_DE: R9.1, U4.24 (PB11); also elsewhere on the board
/rs422/RS422_RE: U4.22 (PB10); also elsewhere on the board
/stm32g4/NRST: C11.1, SWD1.2, U4.7 (PG10-NRST)
/stm32g4/SWCLK: SWD1.5, U4.37 (PA14)
/stm32g4/SWDIO: SWD1.3, U4.36 (PA13)
GND: C10.2, C11.2, C12.2, C13.2, C14.2, C15.2, C16.2, C17.2, R9.2, R11.2, SWD1.4, U4.49 (EPAD); also elsewhere on the board

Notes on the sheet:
PCB rev divider HI / LO x1 r1 - open / 100k
PCB rev divider PB10 / PB11 family 1 (n1) open / open family 2 (c1) down / open family 3 (x1) open / down

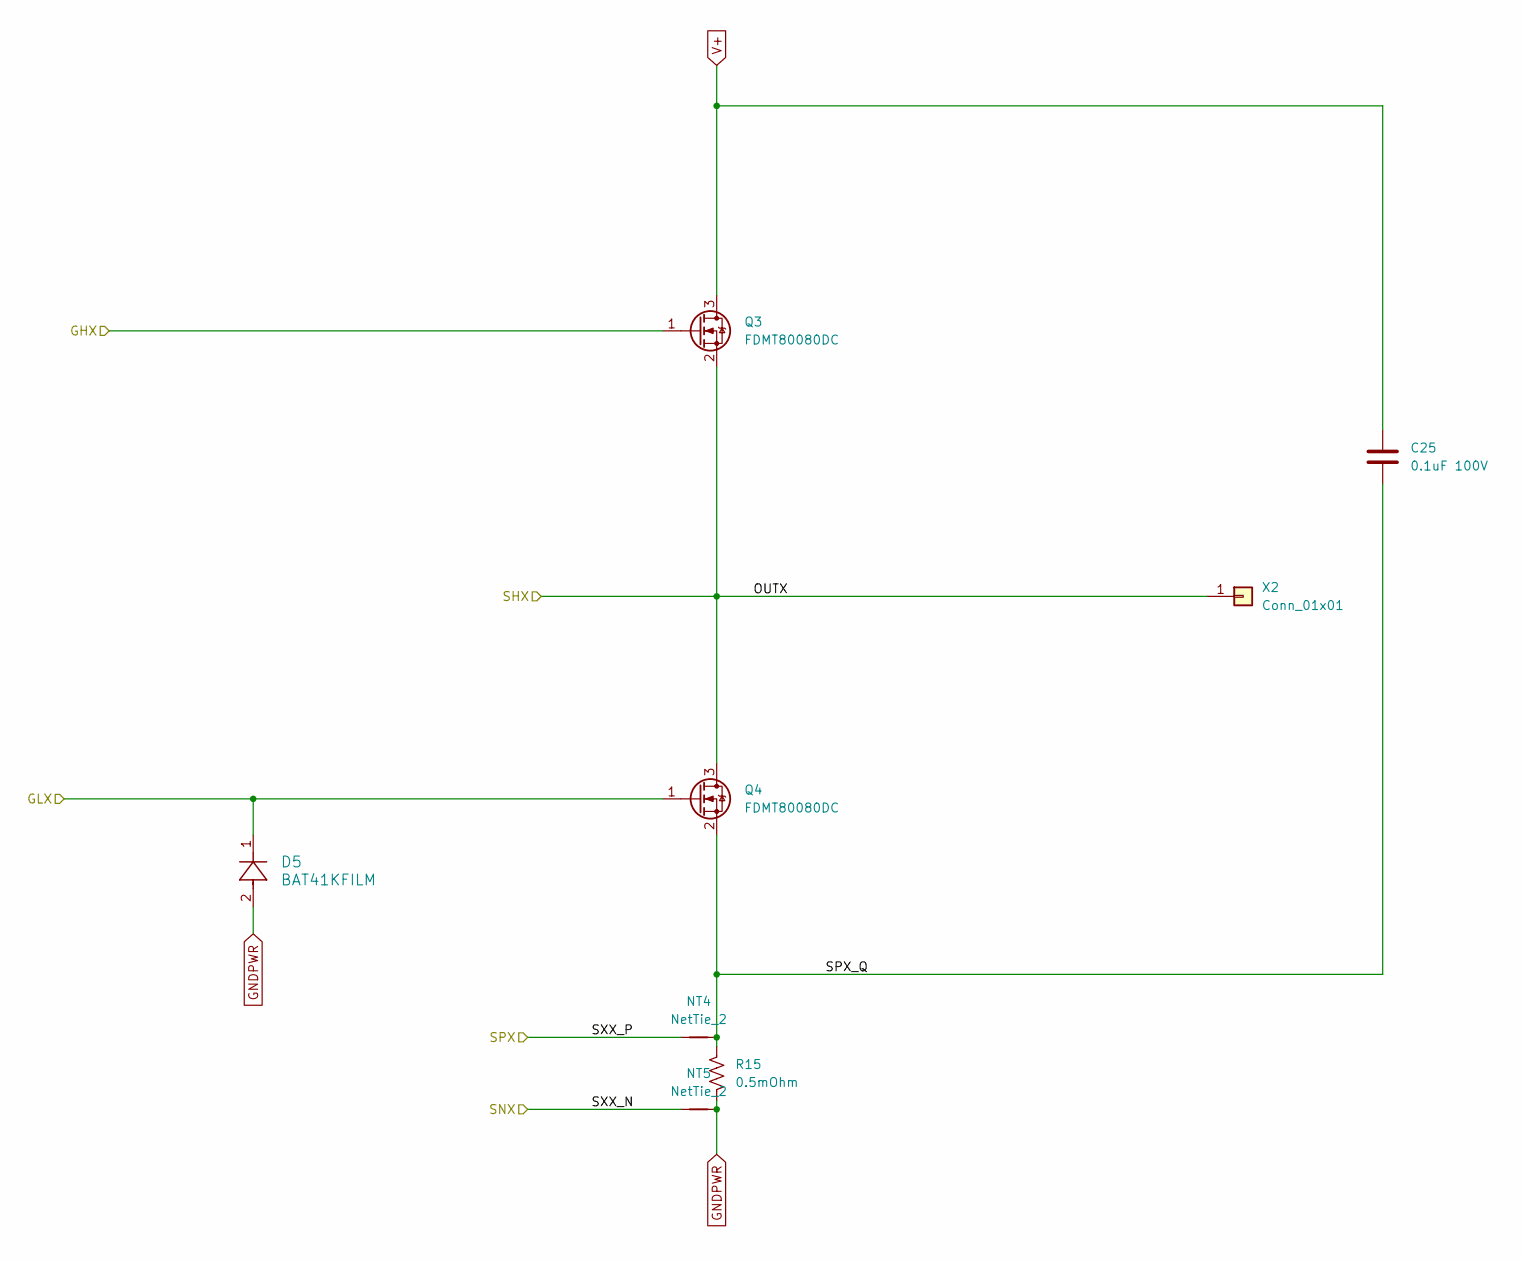
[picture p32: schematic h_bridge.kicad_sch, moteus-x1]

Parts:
C25: 0.1uF 100V; C_1812_4532Metric; MPN 18121C104MAT2A
D5: BAT41KFILM; SOD-523_STM; MPN BAT41KFILM
NT4, NT5: NetTie_2; NetTie-2_SMD_Pad0.2
Q3, Q4: FDMT80080DC; PQFN_8x8; MPN FDMT80080DC
R15: 0.5mOhm; R_2512_6332Metric; MPN WSLF2512L5000FEA
X2: Conn_01x01; POWER_M2.5

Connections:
/Gate Driver/GHB: Q3.1 (G); also elsewhere on the board
/Gate Driver/GLB: D5.1, Q4.1 (G); also elsewhere on the board
/H Bridge B/OUTX: Q3.2 (S), Q4.3 (D), X2.1; also elsewhere on the board
/H Bridge B/SPX_Q: C25.2, NT4.2, Q4.2 (S), R15.1
/H Bridge B/SXX_N: NT5.1; also elsewhere on the board
/H Bridge B/SXX_P: NT4.1; also elsewhere on the board
GNDPWR: D5.2, NT5.2, R15.2; also elsewhere on the board
V+: C25.1, Q3.3 (D); also elsewhere on the board

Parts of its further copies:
C24, C26: 0.1uF 100V; C_1812_4532Metric; MPN 18121C104MAT2A
D4, D6: BAT41KFILM; SOD-523_STM; MPN BAT41KFILM
NT2, NT3, NT6, NT7: NetTie_2; NetTie-2_SMD_Pad0.2
Q1, Q2, Q5, Q6: FDMT80080DC; PQFN_8x8; MPN FDMT80080DC
R14, R16: 0.5mOhm; R_2512_6332Metric; MPN WSLF2512L5000FEA
X1, X3: Conn_01x01; POWER_M2.5

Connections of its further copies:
/Gate Driver/GHA: Q1.1 (G); also elsewhere on the board
/Gate Driver/GHC: Q5.1 (G); also elsewhere on the board
/Gate Driver/GLA: D4.1, Q2.1 (G); also elsewhere on the board
/Gate Driver/GLC: D6.1, Q6.1 (G); also elsewhere on the board
/H Bridge A/OUTX: Q1.2 (S), Q2.3 (D), X1.1; also elsewhere on the board
/H Bridge A/SPX_Q: C24.2, NT2.2, Q2.2 (S), R14.1
/H Bridge A/SXX_N: NT3.1; also elsewhere on the board
/H Bridge A/SXX_P: NT2.1; also elsewhere on the board
/H Bridge C/OUTX: Q5.2 (S), Q6.3 (D), X3.1; also elsewhere on the board
/H Bridge C/SPX_Q: C26.2, NT6.2, Q6.2 (S), R16.1
/H Bridge C/SXX_N: NT7.1; also elsewhere on the board
/H Bridge C/SXX_P: NT6.1; also elsewhere on the board
GNDPWR: D4.2, D6.2, NT3.2, NT7.2, R14.2, R16.2; also elsewhere on the board
V+: C24.1, C26.1, Q1.3 (D), Q5.3 (D); also elsewhere on the board

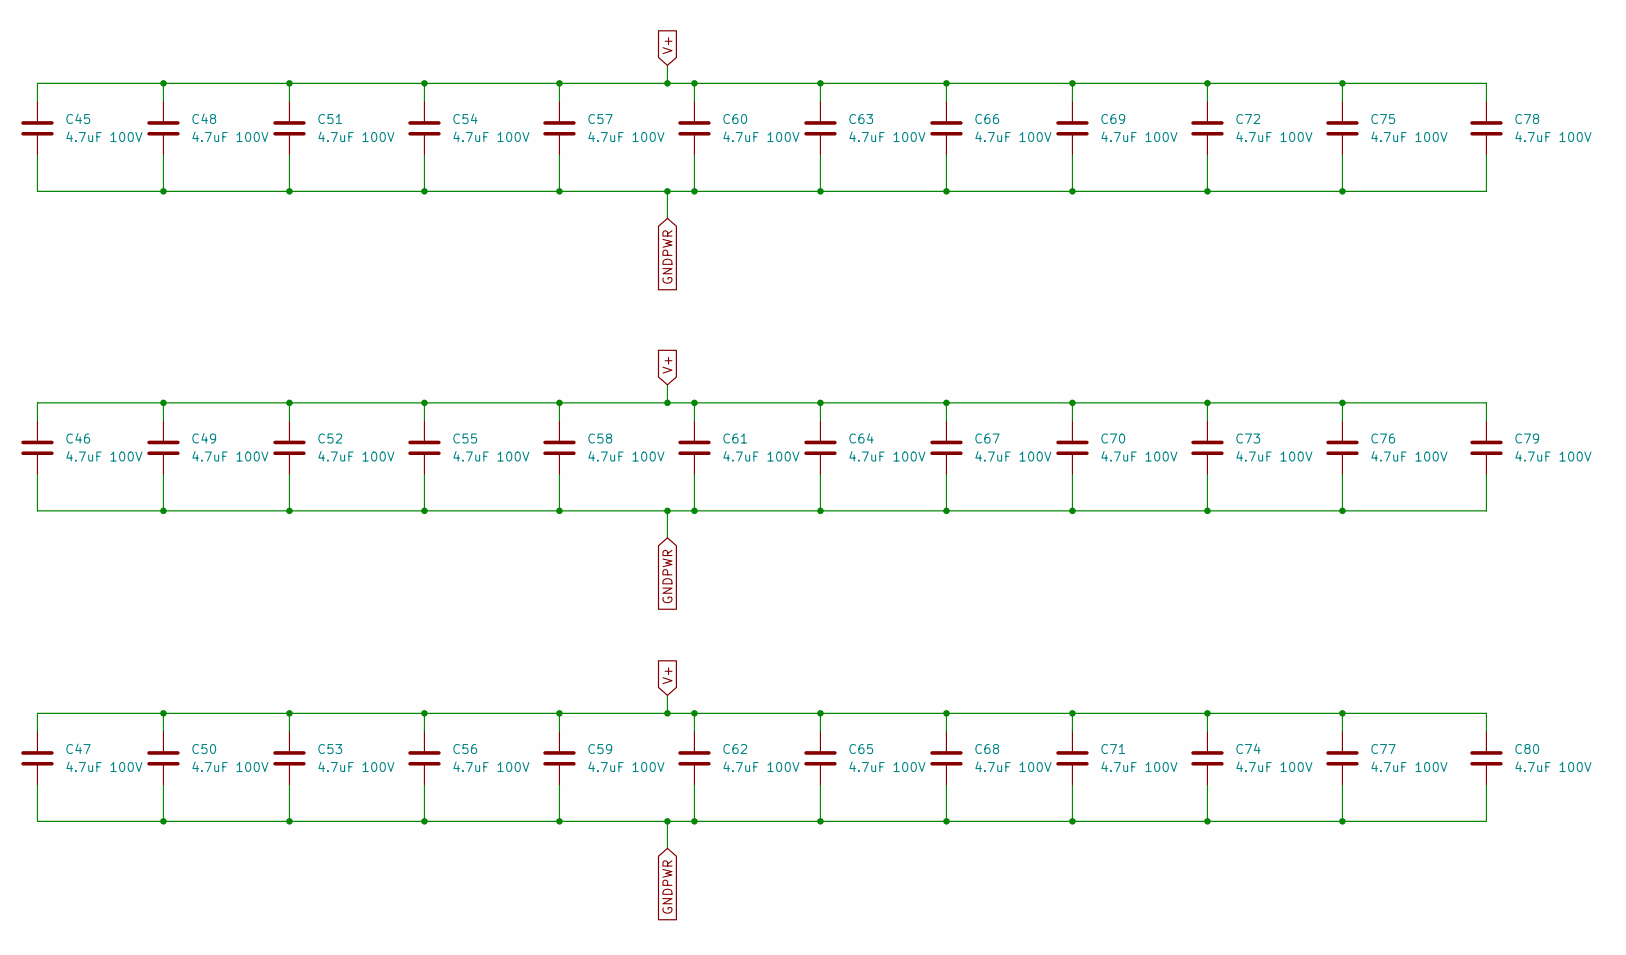
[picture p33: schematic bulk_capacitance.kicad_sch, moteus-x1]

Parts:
C45, C46, C47, C48, C49, C50, C51, C52, C53, C54, C55, C56, C57, C58, C59, C60, C61, C62, C63, C64, C65, C66, C67, C68, C69, C70, C71, C72, C73, C74, C75, C76, C77, C78, C79, C80: 4.7uF 100V; C_1206_3216Metric; MPN GRJ31CC72A475KE01K

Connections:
GNDPWR: C45.2, C46.2, C47.2, C48.2, C49.2, C50.2, C51.2, C52.2, C53.2, C54.2, C55.2, C56.2, C57.2, C58.2, C59.2, C60.2, C61.2, C62.2, C63.2, C64.2, C65.2, C66.2, C67.2, C68.2, C69.2, C70.2, C71.2, C72.2, C73.2, C74.2, C75.2, C76.2, C77.2, C78.2, C79.2, C80.2; also elsewhere on the board
V+: C45.1, C46.1, C47.1, C48.1, C49.1, C50.1, C51.1, C52.1, C53.1, C54.1, C55.1, C56.1, C57.1, C58.1, C59.1, C60.1, C61.1, C62.1, C63.1, C64.1, C65.1, C66.1, C67.1, C68.1, C69.1, C70.1, C71.1, C72.1, C73.1, C74.1, C75.1, C76.1, C77.1, C78.1, C79.1, C80.1; also elsewhere on the board

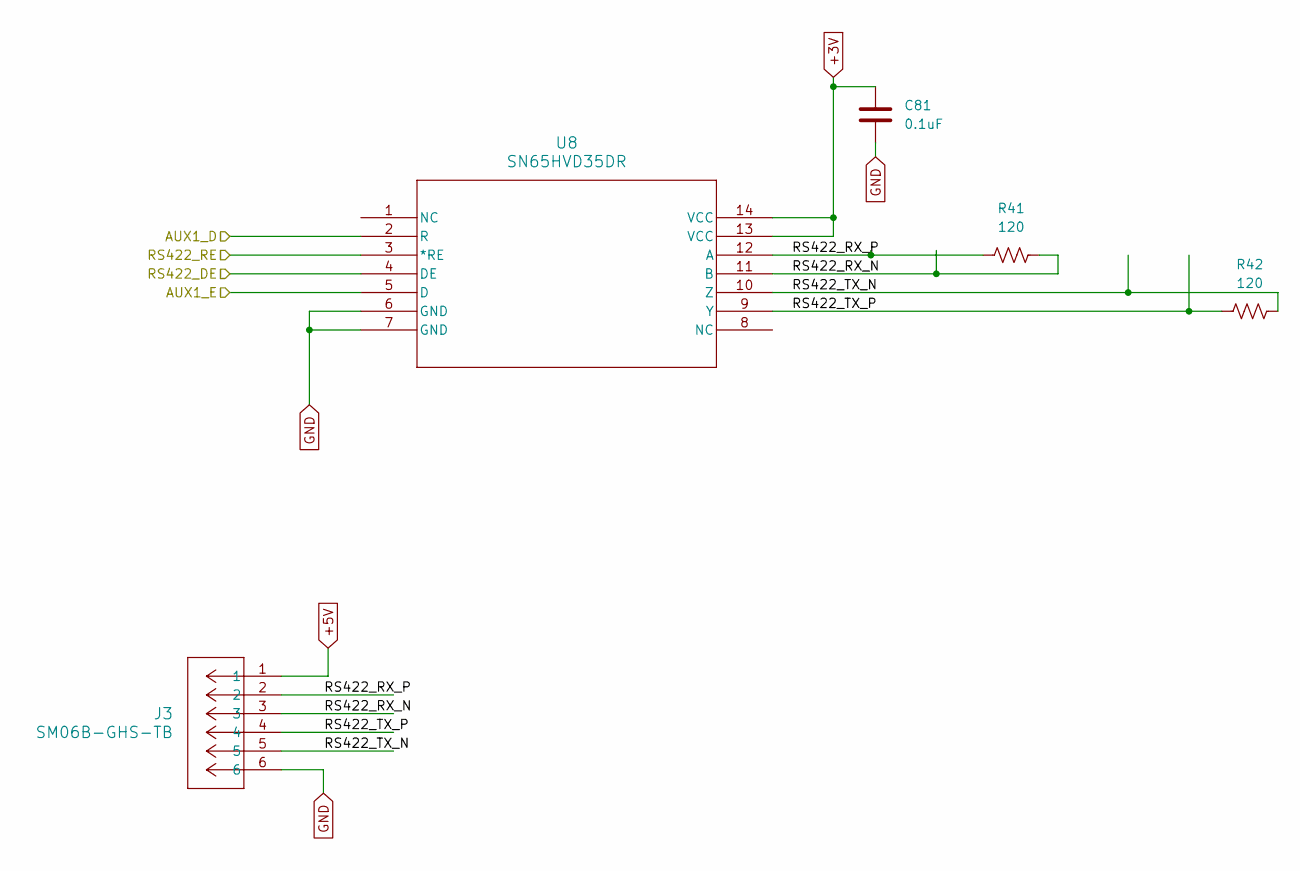
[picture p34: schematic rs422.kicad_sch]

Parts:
C81: 0.1uF; C_0402_1005Metric; MPN MF-CAP-0402-0.1uF
J3: SM06B-GHS-TB; CONN_SM06B-GHS-TB_JST; MPN SM06B-GHS-TB(LF)(SN)
R41, R42: 120; R_0402_1005Metric; MPN RC0402FR-07120RL
U8: SN65HVD35DR; D14; MPN SN65HVD35DR

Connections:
+3V: C81.1, U8.13 (VCC), U8.14 (VCC); also elsewhere on the board
+5V: J3.1; also elsewhere on the board
/aux1/AUX1_D: U8.2 (R); also elsewhere on the board
/aux1/AUX1_E: U8.5 (D); also elsewhere on the board
/rs422/RS422_DE: U8.4 (DE); also elsewhere on the board
/rs422/RS422_RE: U8.3 (*RE); also elsewhere on the board
/rs422/RS422_RX_N: J3.3, R41.2, U8.11 (B)
/rs422/RS422_RX_P: J3.2, R41.1, U8.12 (A)
/rs422/RS422_TX_N: J3.5, R42.2, U8.10 (Z)
/rs422/RS422_TX_P: J3.4, R42.1, U8.9 (Y)
GND: C81.2, J3.6, U8.6 (GND), U8.7 (GND); also elsewhere on the board

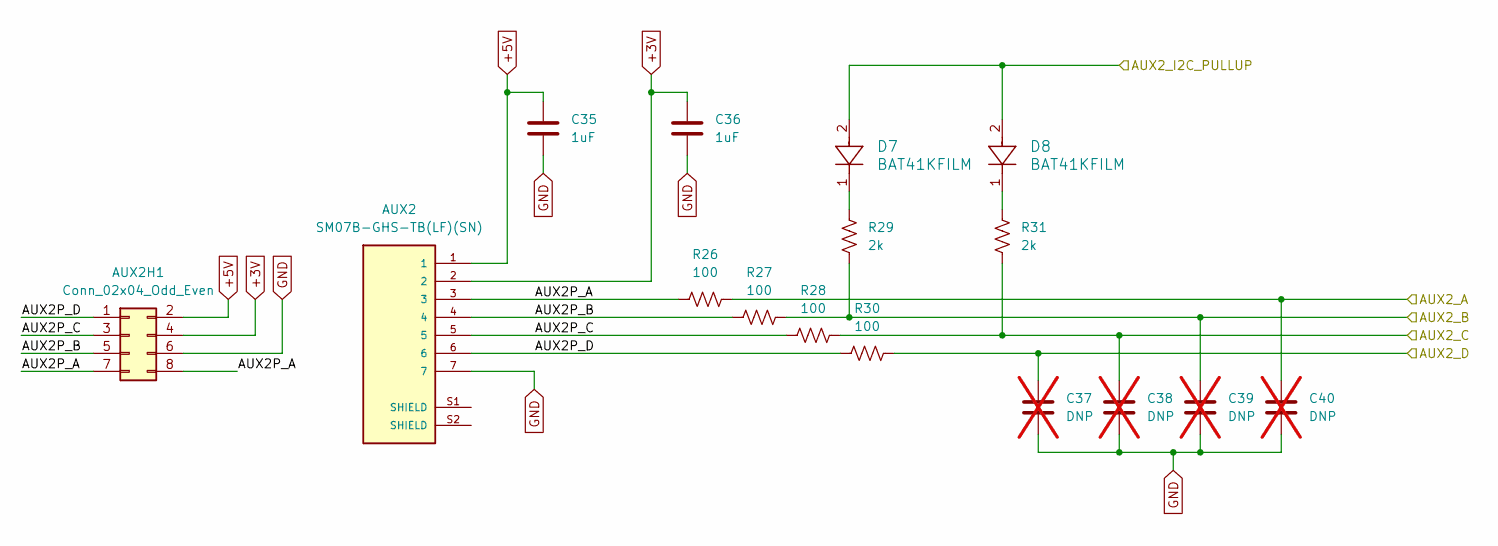
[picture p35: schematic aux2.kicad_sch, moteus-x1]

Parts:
AUX2: SM07B-GHS-TB(LF)(SN); JST_SM07B-GHS-TB(LF)(SN); MPN SM07B-GHS-TB(LF)(SN)
AUX2H1: Conn_02x04_Odd_Even; PinHeader_2x04_P1.27mm_Vertical
C35, C36: 1uF; C_0402_1005Metric; MPN MF-CAP-0402-1uF
C37, C38, C39, C40: DNP; C_0402_1005Metric; not fitted
D7, D8: BAT41KFILM; SOD-523_STM; MPN BAT41KFILM
R26, R27, R28, R30: 100; R_0402_1005Metric; MPN MF-RES-0402-100
R29, R31: 2k; R_0402_1005Metric; MPN MF-RES-0402-2K

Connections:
+3V: AUX2.2, AUX2H1.4, C36.1; also elsewhere on the board
+5V: AUX2.1, AUX2H1.2, C35.1; also elsewhere on the board
/aux2/AUX2P_A: AUX2.3, AUX2H1.7, AUX2H1.8, R26.1
/aux2/AUX2P_B: AUX2.4, AUX2H1.5, R27.1
/aux2/AUX2P_C: AUX2.5, AUX2H1.3, R28.1
/aux2/AUX2P_D: AUX2.6, AUX2H1.1, R30.1
/aux2/AUX2_A: C40.1, R26.2; also elsewhere on the board
/aux2/AUX2_B: C39.1, R27.2, R29.2; also elsewhere on the board
/aux2/AUX2_C: C38.1, R28.2, R31.2; also elsewhere on the board
/aux2/AUX2_D: C37.1, R30.2; also elsewhere on the board
/aux2/AUX2_I2C_PULLUP: D7.2, D8.2; also elsewhere on the board
GND: AUX2.7, AUX2H1.6, C35.2, C36.2, C37.2, C38.2, C39.2, C40.2; also elsewhere on the board
unnamed: D7.1, R29.1
unnamed: D8.1, R31.1

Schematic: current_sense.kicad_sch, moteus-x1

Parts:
C27, C28, C29: 1000pF; C_0402_1005Metric; MPN MF-CAP-0402-1nF
R17, R18, R19: 22; R_0402_1005Metric; MPN MF-RES-0402-22

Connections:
/Current Sense/CUR1: R17.1; also elsewhere on the board
/Current Sense/CUR2: R18.1; also elsewhere on the board
/Current Sense/CUR3: R19.1; also elsewhere on the board
/Current Sense/FCUR1: C27.1, R17.2; also elsewhere on the board
/Current Sense/FCUR2: C28.1, R18.2; also elsewhere on the board
/Current Sense/FCUR3: C29.1, R19.2; also elsewhere on the board
GND: C27.2, C28.2, C29.2; also elsewhere on the board

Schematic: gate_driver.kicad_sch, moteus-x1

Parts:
C18: 1uF; C_0603_1608Metric; MPN MF-CAP-0603-1uF
C19: 0.1uF 100V; C_0603_1608Metric; MPN GCJ188R72A104KA01D
C20: 1uF; C_0402_1005Metric; MPN MF-CAP-0402-1uF
C21: 1uF 25V; C_0603_1608Metric; MPN C1608X7R1E105K080AE
C22: 47nF 100V; C_0603_1608Metric; MPN C0603X473K1RAC7867
C23: 1uF; C_0603_1608Metric; MPN C1608X7R1E105K080AE
R12, R13: 2k; R_0402_1005Metric; MPN MF-RES-0402-2K
U5: DRV8353SRTAR; RTA0040B; MPN DRV8353SRTAR

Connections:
+3V: C18.2, R12.1, R13.1, U5.24 (VREF); also elsewhere on the board
+12V: C19.2, U5.3 (VM); also elsewhere on the board
/Current Sense/CUR1: U5.21 (SOC); also elsewhere on the board
/Current Sense/CUR2: U5.22 (SOB); also elsewhere on the board
/Current Sense/CUR3: U5.23 (SOA); also elsewhere on the board
/Gate Driver/CPH: C22.2, U5.2 (CPH)
/Gate Driver/CPL: C22.1, U5.1 (CPL)
/Gate Driver/DRV8323_CS: U5.30 (SCS_N); also elsewhere on the board
/Gate Driver/DRV8323_FAULT: R13.2, U5.26 (FAULT_N); also elsewhere on the board
/Gate Driver/DRV8323_MISO: R12.2, U5.27 (SDO); also elsewhere on the board
/Gate Driver/DRV8323_MOSI: U5.28 (SDI); also elsewhere on the board
/Gate Driver/DRV8323_SCLK: U5.29 (SCLK); also elsewhere on the board
/Gate Driver/GHA: U5.6 (GHA); also elsewhere on the board
/Gate Driver/GHB: U5.15 (GHB); also elsewhere on the board
/Gate Driver/GHC: U5.16 (GHC); also elsewhere on the board
/Gate Driver/GLA: U5.8 (GLA); also elsewhere on the board
/Gate Driver/GLB: U5.13 (GLB); also elsewhere on the board
/Gate Driver/GLC: U5.18 (GLC); also elsewhere on the board
/Gate Driver/MOTOR1: U5.32 (INHA); also elsewhere on the board
/Gate Driver/MOTOR2: U5.34 (INHB); also elsewhere on the board
/Gate Driver/MOTOR3: U5.36 (INHC); also elsewhere on the board
/Gate Driver/MOTOR_ENABLE: U5.31 (ENABLE); also elsewhere on the board
/Gate Driver/MOTOR_HIZ: U5.33 (INLA), U5.35 (INLB), U5.37 (INLC); also elsewhere on the board
/H Bridge A/OUTX: U5.7 (SHA); also elsewhere on the board
/H Bridge A/SXX_N: U5.10 (SNA); also elsewhere on the board
/H Bridge A/SXX_P: U5.9 (SPA); also elsewhere on the board
/H Bridge B/OUTX: U5.14 (SHB); also elsewhere on the board
/H Bridge B/SXX_N: U5.11 (SNB); also elsewhere on the board
/H Bridge B/SXX_P: U5.12 (SPB); also elsewhere on the board
/H Bridge C/OUTX: U5.17 (SHC); also elsewhere on the board
/H Bridge C/SXX_N: U5.20 (SNC); also elsewhere on the board
/H Bridge C/SXX_P: U5.19 (SPC); also elsewhere on the board
GND: C18.1, C20.1, C23.1, U5.25 (AGND); also elsewhere on the board
GNDPWR: C19.1, U5.39 (PGND), U5.41 (PAD); also elsewhere on the board
unnamed: C20.2, U5.38 (DVDD)
unnamed: C21.2, U5.5 (VCP)
unnamed: C23.2, U5.40 (VGLS)
V+: C21.1, U5.4 (VDRAIN); also elsewhere on the board

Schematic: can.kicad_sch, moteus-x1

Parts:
C30, C31: 0.1uF; C_0402_1005Metric; MPN MF-CAP-0402-0.1uF
CAN1, CAN2: S3B-PH-SM4-TB(LF)(SN); JST_S3B-PH-SM4-TB(LF)(SN); MPN S3B-PH-SM4-TB(LF)(SN)
CAN_DBG1: Conn_01x03_Pin; PinHeader_1x03_P2.00mm_Vertical
R20: 120; R_0603_1608Metric; not fitted
U6: TCAN1057AEV-Q1; SOIC-8_3.9x4.9mm_P1.27mm; MPN TCAN1057AEVDRQ1

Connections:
+3V: C30.1, U6.5 (VIO); also elsewhere on the board
+5V: C31.1, U6.3 (VCC); also elsewhere on the board
/CAN/CAN_N: CAN1.2, CAN2.2, CAN_DBG1.2, R20.2, U6.6 (CANL)
/CAN/CAN_P: CAN1.1, CAN2.1, CAN_DBG1.1, R20.1, U6.7 (CANH)
/CAN/CAN_RX: U6.4 (RXD); also elsewhere on the board
/CAN/CAN_TX: U6.1 (TXD); also elsewhere on the board
GND: C30.2, C31.2, CAN1.3, CAN2.3, CAN_DBG1.3, U6.2 (GND), U6.8 (STB), U6.9 (PAD); also elsewhere on the board

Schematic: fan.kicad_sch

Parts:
C82: 4.7uF; C_1206_3216Metric; MPN GRJ31CC72A475KE01K
FAN1: Conn_01x04_Pin; PinSocket_2x02_P2.54mm_Vertical
R43, R44: 100; R_0402_1005Metric; MPN MF-RES-0402-100

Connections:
+12V: C82.1, FAN1.2; also elsewhere on the board
/aux2/AUX2_C: R43.1; also elsewhere on the board
/aux2/AUX2_D: R44.1; also elsewhere on the board
GND: C82.2, FAN1.1; also elsewhere on the board
unnamed: FAN1.3, R44.2
unnamed: FAN1.4, R43.2

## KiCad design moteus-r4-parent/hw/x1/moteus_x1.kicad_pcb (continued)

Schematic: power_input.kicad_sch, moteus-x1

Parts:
C1: 1uF 100V; C_0805_2012Metric; MPN GCM21BC72A105KE36L
C2: 0.1uF 100V; C_0603_1608Metric; MPN GCJ188R72A104KA01D
C3, C6: 1uF; C_0402_1005Metric; MPN MF-CAP-0402-1uF
C4, C7, C9: 22uF; C_1210_3225Metric; MPN GRM32ER71E226KE15L
C5: 5600pF; C_0402_1005Metric; MPN GCM155R71E562KA37D
C8: DNP; C_0402_1005Metric; not fitted
D3: SMBJ51D-M3/I; D_SMB; MPN SMBJ51D-M3/I
D13: US1B; D_SMA; MPN STPS1H100A
J1: XT30PW-M; AMASS_XT30PW-M; MPN XT30PW-M
J4: Conn_01x02_Pin; PinHeader_1x02_P2.00mm_Vertical
L1, L3: 2.2uH; IND_DFE252012_MUR; MPN DFE252012PD-2R2M=P2
L2: 100uH; IND_6028-WE-LQS_WRE; MPN 74404063101
M1, M2, M3, M4: Conn_01x01_Pin; M3_MOUNT_CORNER
NT1: NetTie_2; NetTie-2_SMD_Pad0.254mm
R1: 42.2k 1%; R_0402_1005Metric; MPN RC0402FR-0742K2L
R2: 69.8k 1%; R_0402_1005Metric; MPN RC0402FR-0769K8L
R3: 80.6k 1%; R_0402_1005Metric; MPN RC0402FR-0780K6L
R4: 22; R_0402_1005Metric; MPN MF-RES-0402-22
R5: 52.3k 1%; R_0402_1005Metric; MPN RC0402FR-0752K3L
R6: 226k 1%; R_0402_1005Metric; MPN RC0402FR-07226KL
R7: 16.2k 1%; R_0402_1005Metric; MPN RC0402FR-0716K2L
R8: DNP; R_0402_1005Metric; not fitted
TP1, TP2, TP3: TestPoint; TestPoint_THTPad_D1.5mm_Drill0.7mm
U1: MAX17760ATC+; 21-0664E_1233-1C_MXM; MPN MAX17760ATC+
U2, U3: TPS629203DRLR; SOT-5x3_DRL0008A_TEX; MPN TPS629203DRLR
VN1: Conn_01x01; POWER_M2.5
VP1: Conn_01x01; POWER_M2.5

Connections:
+3V: C9.1, L3.1, TP3.1, U3.3 (VOS); also elsewhere on the board
+5V: C4.1, D13.1 (K), L1.1, TP1.1, U2.3 (VOS), U3.6 (VIN), U3.7 (EN); also elsewhere on the board
+12V: C7.1, L2.1, R4.2, R6.1, TP2.1, U2.6 (VIN), U2.7 (EN); also elsewhere on the board
/Power Input/5V_IN: D13.2 (A), J4.1
GND: C4.2, C6.2, C7.2, C9.2, J4.2, NT1.2, R1.2, R3.2, R5.2, R7.2, U2.5 (GND), U3.5 (GND); also elsewhere on the board
GNDPWR: C1.2, C2.2, C3.2, C5.2, C8.2, D3.2 (A2), J1.N, NT1.1, R2.2, R8.2, U1.2 (PGND), U1.10 (MODE), U1.11 (SGND), U1.13 (EPAD), VN1.1; also elsewhere on the board
MOUNT_GND: C8.1, M4.1, R8.1
unnamed: C6.1, R4.1, U1.7 (EXTVCC)
unnamed: R6.2, R7.1, U1.8 (FB)
unnamed: L2.2, U1.12 (LX)
unnamed: R2.1, U1.6 (RT/SYNC)
unnamed: C5.1, U1.9 (SS)
unnamed: C3.1, U1.3 (VCC)
unnamed: R3.1, U2.1 (FB/VSET)
unnamed: R1.1, U2.8 (MODE/S-CONF)
unnamed: L1.2, U2.4 (SW)
unnamed: R5.1, U3.8 (MODE/S-CONF)
unnamed: L3.2, U3.4 (SW)
V+: C1.1, C2.1, D3.1 (A1), J1.P, U1.1 (VIN), VP1.1; also elsewhere on the board

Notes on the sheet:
FB: VSET FSW: 2.5MHz Output Discharge: No Mode: Auto PFM
FB: VSET FSW: 2.5MHz Output Discharge: No Mode: FPWM
0.9ms soft start
OPEN = 3.3V
400kHz

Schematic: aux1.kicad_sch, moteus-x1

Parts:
AUX1: SM08B-GHS-TB; CONN_SM08B-GHS-TB_JST; MPN SM08B-GHS-TB(LF)(SN)
AUX1_S1: Conn_01x04; PinHeader_1x04_P1.27mm_Vertical
C41, C42, C43: 1uF; C_0402_1005Metric; MPN MF-CAP-0402-1uF
C44: 0.1uF; C_0402_1005Metric; MPN MF-CAP-0402-0.1uF
D9, D10: BAT41KFILM; SOD-523_STM; MPN BAT41KFILM
R32, R33, R34, R35, R36: 100; R_0402_1005Metric; MPN MF-RES-0402-100
R37, R38: 2k; R_0402_1005Metric; MPN MF-RES-0402-2K
U7: MA600; QFN-16-1EP_3x3mm_P0.5mm_EP1.75x1.75mm; MPN MA600GQE-0000

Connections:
+3V: AUX1.2, AUX1_S1.1, C42.1, C43.1, C44.1, U7.13 (VDD), U7.14 (AVDD); also elsewhere on the board
+5V: AUX1.1, C41.1; also elsewhere on the board
/aux1/AS5047_CS: U7.5 (~CS); also elsewhere on the board
/aux1/AUX1P_A: AUX1.3, R32.1
/aux1/AUX1P_B: AUX1.4, R33.1
/aux1/AUX1P_C: AUX1.5, R34.1
/aux1/AUX1P_D: AUX1.6, AUX1_S1.2, R35.1
/aux1/AUX1P_E: AUX1.7, AUX1_S1.3, R36.1
/aux1/AUX1_A: R32.2, U7.12 (SCLK); also elsewhere on the board
/aux1/AUX1_B: R33.2, U7.7 (MISO); also elsewhere on the board
/aux1/AUX1_C: R34.2, U7.4 (MOSI); also elsewhere on the board
/aux1/AUX1_D: R35.2, R37.2; also elsewhere on the board
/aux1/AUX1_E: R36.2, R38.2; also elsewhere on the board
/aux1/AUX1_I2C_PULLUP: D9.2, D10.2; also elsewhere on the board
GND: AUX1.8, AUX1_S1.4, C41.2, C42.2, C43.2, C44.2, U7.8 (GND), U7.10 (TEST); also elsewhere on the board
unnamed: D9.1, R37.1
unnamed: D10.1, R38.1



Board: 6 copper layers, 56.0 x 56.0 mm, 187 parts (108 on the bottom side), 106 nets.

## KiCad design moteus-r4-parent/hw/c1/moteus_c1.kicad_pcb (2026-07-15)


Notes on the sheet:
moteus-c1 (c) mjbots Robotic Systems, LLC - info@mjbots.com - 2024 Licensed under the Apache 2.0 License


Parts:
C28, C29, C30: 0.1uF; C_0402_1005Metric; MPN MF-CAP-0402-0.1uF
R17: 100k 1%; R_0402_1005Metric; MPN RC0402FR-07100KL
R18, R21: 10k 1%; R_0402_1005Metric; MPN RC0402FR-0710KL
R19: 4.7k 1%; R_0402_1005Metric; MPN RC0402FR-074K7L
R20: 47k NTC; R_0402_1005Metric; MPN NCP15WB473F03RC
TEMP1: Conn_01x02_Pin; PinHeader_1x02_P2.00mm_Vertical

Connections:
/VT Sense/VBAT_SENSE: C29.1, R17.2, R19.1; also elsewhere on the board
/VT Sense/VTEMP_FET: C30.1, R20.2, R21.1; also elsewhere on the board
/VT Sense/VTEMP_MOT: C28.1, R18.1, TEMP1.2; also elsewhere on the board
V+: R17.1; also elsewhere on the board


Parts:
D13: LED; LED_0603_1608Metric; MPN MF-LED-0603-RED
D14: LED; LED_0603_1608Metric; MPN MF-LED-0603-GREEN
R29, R30: 560; R_0402_1005Metric; MPN MF-RES-0402-560
TP1: TestPoint; TestPoint_THTPad_D1.0mm_Drill0.5mm

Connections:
/LED Sense/LED1: D13.1 (K); also elsewhere on the board
/LED Sense/LED2: D14.1 (K); also elsewhere on the board
unnamed: D13.2 (A), R29.2
unnamed: D14.2 (A), R30.2


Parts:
C6, C9, C11, C12, C13: 0.1uF; C_0402_1005Metric; MPN MF-CAP-0402-0.1uF
C7: 10uF; C_1206_3216Metric; MPN MF-CAP-1206-10uF
C8: 4.7uF; C_0603_1608Metric; MPN CL10A475KP8NNNC
C10: 1uF; C_0402_1005Metric; MPN MF-CAP-0402-1uF
R2: 2k; R_0402_1005Metric; MPN MF-RES-0402-2K
SWD1: S6B-ZR-SM4A-TF(LF)(SN); JST_S6B-ZR-SM4A-TF(LF)(SN); MPN S6B-ZR-SM4A-TF(LF)(SN)
U3: STM32G474CEU6; UFQFPN-48_7X7X0P55MM; MPN STM32G474CEU6

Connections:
/CAN/CAN_RX: U3.43 (PB5); also elsewhere on the board
/CAN/CAN_TX: U3.44 (PB6); also elsewhere on the board
/Current Sense/FCUR1: U3.11 (PA3); also elsewhere on the board
/Current Sense/FCUR2: U3.14 (PA6); also elsewhere on the board
/Current Sense/FCUR3: U3.18 (PB1); also elsewhere on the board
/Gate Driver/DRV8323_CS: U3.17 (PB0); also elsewhere on the board
/Gate Driver/DRV8323_FAULT: U3.26 (PB13); also elsewhere on the board
/Gate Driver/DRV8323_MOSI: U3.2 (PC13); also elsewhere on the board
/Gate Driver/DRV8323_SCLK: U3.39 (PC10); also elsewhere on the board
/Gate Driver/MOTOR1: U3.8 (PA0); also elsewhere on the board
/Gate Driver/MOTOR2: U3.9 (PA1); also elsewhere on the board
/Gate Driver/MOTOR3: U3.10 (PA2); also elsewhere on the board
/Gate Driver/MOTOR_ENABLE: U3.3 (PC14-OSC32_IN); also elsewhere on the board
/Gate Driver/MOTOR_HIZ: U3.4 (PC15-OSC32_OUT); also elsewhere on the board
/LED Sense/LED1: U3.28 (PB15); also elsewhere on the board
/LED Sense/LED2: U3.29 (PC6); also elsewhere on the board
/VT Sense/VBAT_SENSE: U3.31 (PA9); also elsewhere on the board
/VT Sense/VTEMP_FET: U3.25 (PB12); also elsewhere on the board
/VT Sense/VTEMP_MOT: U3.30 (PA8); also elsewhere on the board
/aux1/AS5047_CS: U3.19 (PB2); also elsewhere on the board
/aux1/AUX1_A: U3.13 (PA5); also elsewhere on the board
/aux1/AUX1_B: U3.42 (PB4); also elsewhere on the board
/aux1/AUX1_C: U3.15 (PA7); also elsewhere on the board
/aux1/AUX1_D: U3.38 (PA15); also elsewhere on the board
/aux1/AUX1_E: U3.41 (PB3), U3.47 (PB9); also elsewhere on the board
/aux2/AUX2_A: U3.6 (PF1-OSC_OUT); also elsewhere on the board
/aux2/AUX2_B: U3.5 (PF0-OSC_IN), U3.32 (PA10); also elsewhere on the board
/aux2/AUX2_C: U3.16 (PC4), U3.33 (PA11); also elsewhere on the board
/aux2/AUX2_D: U3.45 (PB7); also elsewhere on the board
/aux2/AUX2_I2C_PULLUP: U3.34 (PA12); also elsewhere on the board
/stm32g4/AUX1_I2C_PULLUP: U3.46 (PB8-BOOT0)
/stm32g4/NRST: C6.1, SWD1.2, U3.7 (PG10-NRST)
/stm32g4/SWCLK: SWD1.5, U3.37 (PA14)
/stm32g4/SWDIO: SWD1.3, U3.36 (PA13)

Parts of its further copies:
R31: 2k; R_0402_1005Metric; MPN MF-RES-0402-2K

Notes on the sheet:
PB10 is disconnected on r4.5/r4.8/r4.11 PB10 is RS422 receive enable output on n1 It is tied to ground here to detect we are a c1 board
PCB rev divider HI / LO r1.0 - open / open (should not have been all open) r1.1 - open / 100k
AUX1_A (but only for external)


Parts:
C19: 0.1uF 100V; C_1206_3216Metric; MPN 12061C104KAT2A
D4: BAT41KFILM; SOD-523_STM; MPN BAT41KFILM
NT2, NT3: NetTie_2; NetTie-2_SMD_Pad0.2
Q1, Q2: TPN19008QM_LQ; TSON Advance_TOS; MPN TPN19008QM,LQ
R6: 2mOhm; R_0805_2012Metric; MPN CSSH0805FT2L00
X1: Conn_01x01; POWER_M2.5

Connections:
/Gate Driver/GHA: Q1.4 (GATE); also elsewhere on the board
/Gate Driver/GLA: D4.1, Q2.4 (GATE); also elsewhere on the board
/H Bridge A/OUTX: Q1.1 (SOURCE), Q1.2 (SOURCE), Q1.3 (SOURCE), Q2.5 (DRAIN), Q2.6 (DRAIN), Q2.7 (DRAIN), Q2.8 (DRAIN), X1.1; also elsewhere on the board
/H Bridge A/SPX_Q: C19.2, NT2.2, Q2.1 (SOURCE), Q2.2 (SOURCE), Q2.3 (SOURCE), R6.1
/H Bridge A/SXX_N: NT3.1; also elsewhere on the board
/H Bridge A/SXX_P: NT2.1; also elsewhere on the board
GNDPWR: D4.2, NT3.2, R6.2; also elsewhere on the board
V+: C19.1, Q1.5 (DRAIN), Q1.6 (DRAIN), Q1.7 (DRAIN), Q1.8 (DRAIN); also elsewhere on the board

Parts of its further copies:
C20, C21: 0.1uF 100V; C_1206_3216Metric; MPN 12061C104KAT2A
D7, D10: BAT41KFILM; SOD-523_STM; MPN BAT41KFILM
NT4, NT5, NT6, NT7: NetTie_2; NetTie-2_SMD_Pad0.2
Q3, Q4, Q5, Q6: TPN19008QM_LQ; TSON Advance_TOS; MPN TPN19008QM,LQ
R9, R12: 2mOhm; R_0805_2012Metric; MPN CSSH0805FT2L00
X2, X3: Conn_01x01; POWER_M2.5

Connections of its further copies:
/Gate Driver/GHB: Q3.4 (GATE); also elsewhere on the board
/Gate Driver/GHC: Q5.4 (GATE); also elsewhere on the board
/Gate Driver/GLB: D7.1, Q4.4 (GATE); also elsewhere on the board
/Gate Driver/GLC: D10.1, Q6.4 (GATE); also elsewhere on the board
/H Bridge B/OUTX: Q3.1 (SOURCE), Q3.2 (SOURCE), Q3.3 (SOURCE), Q4.5 (DRAIN), Q4.6 (DRAIN), Q4.7 (DRAIN), Q4.8 (DRAIN), X2.1; also elsewhere on the board
/H Bridge B/SPX_Q: C20.2, NT4.2, Q4.1 (SOURCE), Q4.2 (SOURCE), Q4.3 (SOURCE), R9.1
/H Bridge B/SXX_N: NT5.1; also elsewhere on the board
/H Bridge B/SXX_P: NT4.1; also elsewhere on the board
/H Bridge C/OUTX: Q5.1 (SOURCE), Q5.2 (SOURCE), Q5.3 (SOURCE), Q6.5 (DRAIN), Q6.6 (DRAIN), Q6.7 (DRAIN), Q6.8 (DRAIN), X3.1; also elsewhere on the board
/H Bridge C/SPX_Q: C21.2, NT6.2, Q6.1 (SOURCE), Q6.2 (SOURCE), Q6.3 (SOURCE), R12.1
/H Bridge C/SXX_N: NT7.1; also elsewhere on the board
/H Bridge C/SXX_P: NT6.1; also elsewhere on the board
GNDPWR: D7.2, D10.2, NT5.2, NT7.2, R9.2, R12.2; also elsewhere on the board
V+: C20.1, C21.1, Q3.5 (DRAIN), Q3.6 (DRAIN), Q3.7 (DRAIN), Q3.8 (DRAIN), Q5.5 (DRAIN), Q5.6 (DRAIN), Q5.7 (DRAIN), Q5.8 (DRAIN); also elsewhere on the board


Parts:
C38, C39, C40, C41, C42, C43, C44, C45, C46, C47, C48, C49: 4.7uF 100V; C_1206_3216Metric; MPN GRJ31CC72A475KE01K

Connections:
GNDPWR: C38.2, C39.2, C40.2, C41.2, C42.2, C43.2, C44.2, C45.2, C46.2, C47.2, C48.2, C49.2; also elsewhere on the board
V+: C38.1, C39.1, C40.1, C41.1, C42.1, C43.1, C44.1, C45.1, C46.1, C47.1, C48.1, C49.1; also elsewhere on the board


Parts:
AUX2: SM07B-GHS-TB(LF)(SN); JST_SM07B-GHS-TB(LF)(SN); MPN SM07B-GHS-TB(LF)(SN)
AUX2H1: Conn_02x04_Odd_Even; PinHeader_2x04_P1.27mm_Vertical
C31, C32: 1uF; C_0402_1005Metric; MPN MF-CAP-0402-1uF
C33, C34, C35, C36: DNP; C_0402_1005Metric; not fitted
D11, D12: BAT41KFILM; SOD-523_STM; MPN BAT41KFILM
R22, R23: 2k; R_0402_1005Metric; MPN MF-RES-0402-2K
R24, R25, R26, R27: 100; R_0402_1005Metric; MPN MF-RES-0402-100

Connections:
+5V: AUX2.1, AUX2H1.2, C31.1; also elsewhere on the board
/aux2/AUX2P_B: AUX2.4, AUX2H1.5, R25.1
/aux2/AUX2P_C: AUX2.5, AUX2H1.3, R26.1
/aux2/AUX2P_D: AUX2.6, AUX2H1.1, R27.1
/aux2/AUX2_A: C36.1, R24.2; also elsewhere on the board
/aux2/AUX2_B: C35.1, R22.2, R25.2; also elsewhere on the board
/aux2/AUX2_C: C34.1, R23.2, R26.2; also elsewhere on the board
/aux2/AUX2_D: C33.1, R27.2; also elsewhere on the board
/aux2/AUX2_I2C_PULLUP: D11.2, D12.2; also elsewhere on the board
unnamed: D11.1, R22.1
unnamed: D12.1, R23.1


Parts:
C23, C24, C25: 1000pF; C_0402_1005Metric; MPN MF-CAP-0402-1nF
R13, R14, R15: 22; R_0402_1005Metric; MPN MF-RES-0402-22

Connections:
/Current Sense/CUR1: R13.1; also elsewhere on the board
/Current Sense/CUR2: R14.1; also elsewhere on the board
/Current Sense/CUR3: R15.1; also elsewhere on the board
/Current Sense/FCUR1: C23.1, R13.2; also elsewhere on the board
/Current Sense/FCUR2: C24.1, R14.2; also elsewhere on the board
/Current Sense/FCUR3: C25.1, R15.2; also elsewhere on the board

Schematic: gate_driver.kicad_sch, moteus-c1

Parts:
C14: 1uF 25V; C_0603_1608Metric; MPN C1608X7R1E105K080AE
C15: 0.1uF 100V; C_0603_1608Metric; MPN GCJ188R72A104KA01D
C16: 47nF 100V; C_0603_1608Metric; MPN C0603X473K1RAC7867
C17: 1uF; C_0402_1005Metric; MPN MF-CAP-0402-1uF
C18: 1uF; C_0603_1608Metric; MPN MF-CAP-0603-1uF
R2, R3: 2k; R_0402_1005Metric; MPN MF-RES-0402-2K
U4: DRV8323SRTAR; RTA0040B; MPN DRV8323SRTAR

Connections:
/Current Sense/CUR1: U4.21 (SOC); also elsewhere on the board
/Current Sense/CUR2: U4.22 (SOB); also elsewhere on the board
/Current Sense/CUR3: U4.23 (SOA); also elsewhere on the board
/Gate Driver/DRV8323_CS: U4.29 (GAIN_SCS_N); also elsewhere on the board
/Gate Driver/DRV8323_FAULT: R3.2, U4.25 (FAULT_N); also elsewhere on the board
/Gate Driver/DRV8323_MOSI: U4.27 (IDRIVE_SDI); also elsewhere on the board
/Gate Driver/DRV8323_SCLK: U4.28 (VDS_SCLK); also elsewhere on the board
/Gate Driver/GHA: U4.6 (GHA); also elsewhere on the board
/Gate Driver/GHB: U4.15 (GHB); also elsewhere on the board
/Gate Driver/GHC: U4.16 (GHC); also elsewhere on the board
/Gate Driver/GLA: U4.8 (GLA); also elsewhere on the board
/Gate Driver/GLB: U4.13 (GLB); also elsewhere on the board
/Gate Driver/GLC: U4.18 (GLC); also elsewhere on the board
/Gate Driver/MOTOR1: U4.34 (INHA); also elsewhere on the board
/Gate Driver/MOTOR2: U4.36 (INHB); also elsewhere on the board
/Gate Driver/MOTOR3: U4.38 (INHC); also elsewhere on the board
/Gate Driver/MOTOR_ENABLE: U4.30 (ENABLE); also elsewhere on the board
/Gate Driver/MOTOR_HIZ: U4.35 (INLA), U4.37 (INLB), U4.39 (INLC); also elsewhere on the board
/H Bridge A/OUTX: U4.7 (SHA); also elsewhere on the board
/H Bridge A/SXX_N: U4.10 (SNA); also elsewhere on the board
/H Bridge A/SXX_P: U4.9 (SPA); also elsewhere on the board
/H Bridge B/OUTX: U4.14 (SHB); also elsewhere on the board
/H Bridge B/SXX_N: U4.11 (SNB); also elsewhere on the board
/H Bridge B/SXX_P: U4.12 (SPB); also elsewhere on the board
/H Bridge C/OUTX: U4.17 (SHC); also elsewhere on the board
/H Bridge C/SXX_N: U4.20 (SNC); also elsewhere on the board
/H Bridge C/SXX_P: U4.19 (SPC); also elsewhere on the board
GNDPWR: C15.1, U4.40 (PGND), U4.41 (PAD); also elsewhere on the board
unnamed: C16.2, U4.2 (CPH)
unnamed: C16.1, U4.1 (CPL)
unnamed: C17.2, U4.33 (DVDD)
unnamed: C14.2, U4.3 (VCP)
V+: C14.1, C15.2, U4.4 (VM), U4.5 (VDRAIN); also elsewhere on the board

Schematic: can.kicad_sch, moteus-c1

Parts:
C26, C27: 0.1uF; C_0402_1005Metric; MPN MF-CAP-0402-0.1uF
CAN1: S3B-PH-SM4-TB(LF)(SN); JST_S3B-PH-SM4-TB(LF)(SN); MPN S3B-PH-SM4-TB(LF)(SN)
CAN_DBG1: Conn_01x03_Pin; PinHeader_1x03_P2.00mm_Vertical
R16: 120; R_0603_1608Metric; MPN RC0805FR-07120RL; not fitted
U5: TCAN1057AEV-Q1; SOIC-8_3.9x4.9mm_P1.27mm; MPN TCAN1057AEVDRQ1

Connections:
+5V: C27.1, U5.3 (VCC); also elsewhere on the board
/CAN/CAN_N: CAN1.2, CAN_DBG1.2, R16.2, U5.6 (CANL)
/CAN/CAN_P: CAN1.1, CAN_DBG1.1, R16.1, U5.7 (CANH)
/CAN/CAN_RX: U5.4 (RXD); also elsewhere on the board
/CAN/CAN_TX: U5.1 (TXD); also elsewhere on the board

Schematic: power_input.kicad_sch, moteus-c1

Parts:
C1: 1uF 100V; C_0805_2012Metric; MPN GCM21BC72A105KE36L
C2: 22uF; C_1206_3216Metric; MPN GRM31CR71A226KE15L
C3, C4: 1uF; C_0402_1005Metric; MPN MF-CAP-0402-1uF
C5: 1uF; C_0603_1608Metric; MPN MF-CAP-0603-1uF
C22: DNP; C_0402_1005Metric; not fitted
D1: SMBJ48D-M3/I; D_SMB; MPN SMBJ48D-M3/I
J1: XT30PW-M; AMASS_XT30PW-M; MPN XT30PW-M
L1: 47uH; IND_4018-WE-LQS_WRE; MPN 74404042470
NT1: NetTie_2; NetTie-2_SMD_Pad0.254mm
R1: 0; R_0402_1005Metric; MPN MF-RES-0402-0
R4: DNP; R_0402_1005Metric; not fitted
U1: MAX15062BATA+T; 21-0487A_MXM; MPN MAX15062BATA+T
U2: TLV70233PDBVR; SOT-23-5; MPN TLV70233PDBVR
VN1: Conn_01x01; POWER_M2.5
VP1: Conn_01x01; POWER_M2.5

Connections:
+5V: C2.1, C3.1, L1.1, U1.4 (FB/VOUT), U2.1 (IN), U2.3 (EN); also elsewhere on the board
GNDPWR: C1.2, C5.2, C22.2, D1.2 (A2), J1.N, NT1.1, R4.2, VN1.1; also elsewhere on the board
MOUNT_GND: C22.1, R4.1; also elsewhere on the board
unnamed: L1.2, U1.8 (LX)
unnamed: R1.1, U1.5 (MODE)
unnamed: C5.1, U1.3 (VCC)
V+: C1.1, D1.1 (A1), J1.P, U1.1 (VIN), U1.2 (EN/UVLO), VP1.1; also elsewhere on the board

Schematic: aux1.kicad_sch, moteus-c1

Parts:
AUX1: Conn_01x04; PinHeader_1x04_P1.27mm_Vertical
C37: 0.1uF; C_0402_1005Metric; MPN MF-CAP-0402-0.1uF
R24: 100; R_0402_1005Metric; MPN MF-RES-0402-100
R28: 0; R_0402_1005Metric; MPN MF-RES-0402-0
U6: AS5047P-ATSM; TSSOP14_OSM; MPN AS5047P-ATSM

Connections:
/aux1/AS5047_CS: U6.1 (CSn); also elsewhere on the board
/aux1/AUX1_A: U6.2 (CLK); also elsewhere on the board
/aux1/AUX1_B: U6.3 (MISO); also elsewhere on the board
/aux1/AUX1_C: U6.4 (MOSI); also elsewhere on the board
/aux2/AUX2_A: R24.2; also elsewhere on the board
unnamed: R28.1, U6.11 (VDD)

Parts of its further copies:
R34, R35: 100; R_0402_1005Metric; MPN MF-RES-0402-100

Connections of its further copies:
/aux1/AUX1_D: R34.2; also elsewhere on the board
/aux1/AUX1_E: R35.2; also elsewhere on the board

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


Board: 4 copper layers, 38.0 x 38.0 mm, 125 parts (64 on the bottom side), 83 nets.

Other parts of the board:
MOUNT1, MOUNT2, MOUNT3, MOUNT4: M2.5_MOUNT
R32: DNP; R_0402_1005Metric
R33: 100k; R_0402_1005Metric

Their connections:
MOUNT_GND: MOUNT3.1; also elsewhere on the board

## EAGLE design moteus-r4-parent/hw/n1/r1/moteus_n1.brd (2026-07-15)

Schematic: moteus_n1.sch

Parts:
A: PAD16AWG_TERM; 16AWG_TERM
AUX1: SM08B-GHS-TB(LF)(SN); JST_SM08B-GHS-TB(LF)(SN); MPN SM08B-GHS-TB(LF)(SN)
AUX2: SM07B-GHS-TB(LF)(SN); JST_SM07B-GHS-TB(LF)(SN); MPN SM07B-GHS-TB(LF)(SN)
B: PAD16AWG_TERM; 16AWG_TERM
C: PAD16AWG_TERM; 16AWG_TERM
C1, C18, C19, C20, C21, C24, C25, C26: DNP; C0402
C2: 1uF 100V; C0805; MPN GCM21BC72A105KE36L
C3, C16, C17, C22, C23: 1uF; C0603; MPN MF-CAP-0603-1uF
C4, C13: 10uF; C1206; MPN MF-CAP-1206-10uF
C5, C10, C34, C36, C37: 1uF; C0402; MPN MF-CAP-0402-1uF
C6: 22uF; C1206; MPN CL31B226KPHNNNE
C7, C8, C9, C11, C12, C14, C15, C28, C29, C38: 0.1uF; C0402; MPN MF-CAP-0402-0.1uF
C27: 0.01uF; C0402; MPN MF-CAP-0402-0.01uF
C30, C31, C32: 1000pF; C0402; MPN MF-CAP-0402-1nF
C33, C35: 0.1uF 100V; C0603; MPN GCJ188R72A104KA01D
C39: 0.47uF 100V; C0805; MPN 08051C474KAT2A
C40, C41, C42: 0.1uF 100V; C1206; MPN 12061C104KAT2A
C43, C44: 100uF 63V; EEHZS1V471UP; MANUFACTURER_PART_NUMBER EEH-ZU1J101V
C45, C46, C47: 4.7uF 100V; C1206; MPN GRJ31CC72A475KE01K
C48, C49, C50, C51, C52, C53, C54, C55, C56, C57, C58, C59, C60: 4.7uF 100V; C1206_NOCREAM_NOBORDER; MPN GRJ31CC72A475KE01K
CAN1, CAN2: JST-PH3; JST_S3B-PH-SM4-TB(LF)(SN); MPN S3B-PH-SM4-TB(LF)(SN)
D1: MF-LED-0603-RED; LED0603
D2: MF-LED-0603-RED; LED0603; MPN MF-LED-0603-GREEN
D3, D4, D5, D6, D7, D8, D9, D10, D11: BAT41KFILM; SODFL1608X70N; MPN BAT41KFILM
D12: DIODE-DO214AA; DO214AA; MPN TPSMB51A-VR
D33, D50: PAD24AWG_PAD; 24AWG_PAD
DAC: PAD24AWG_PAD; 24AWG_PAD
DG1: PAD24AWG_PAD; 24AWG_PAD
DTR: PAD24AWG_PAD; 24AWG_PAD
DTX: PAD24AWG_PAD; 24AWG_PAD
J1, J2: XT30XT30PW_MALE; XT30PW_MALE; MPN XT30PW-M
L1: SRN4018-220M; IND_BOURNS_SRN4018; MANUFACTURER_PART_NUMBER 74404042470
L2: 74404024100; IND_4024100_WRE; MPN 74404024100
M1, M2, M3, M4: MOUNT; M2.5MOUNT
MOT1, MOT2, MOT3: PAD24AWG_PAD; 24AWG_PAD
Q1, Q3, Q5: TPH1R204PL_VIAS; SOP_ADVANCE_8_VIAS; MPN TPH2R408QM,L1Q
Q2, Q4, Q6: TPH1R204PLSOP_ADVANCE_8; SOP_ADVANCE_8; MPN TPH2R408QM,L1Q
R1, R2: DNP; R0402
R3, R15: 100k 1%; R0402; MPN RC0402FR-07100KL
R4, R5, R8, R9, R10, R11, R12, R13, R14: 100; R0402; MPN MF-RES-0402-100
R6, R7, R25, R26: 2k; R0402; MPN MF-RES-0402-2K
R16: 4.7k 1%; R0402; MPN RC0402FR-074K7L
R17: 47k NTC; R0402; MPN NCP15WB473F03RC
R18, R19: 10k 1%; R0402; MPN RC0402FR-0710KL
R20, R21: 560; R0402; MPN MF-RES-0402-560
R22, R23, R24: 22; R0402; MPN MF-RES-0402-22
R27, R28, R30, R31, R32: 7.5; R0402; MPN RC0402FR-077R5L
R29: 7.5; R0805; MPN RC0805FR-077R5L
RA: 0.5mOhm 1% 2W; M1206; MPN HCS1206FTL500
RB: 0.5mOhm 1% 2W; M1206; MPN HCS1206FTL500
RC: 0.5mOhm 1% 2W; M1206; MPN HCS1206FTL500
SH1, SH2, SH3: SHORTT5; SHORT_TOP-50
SH4: SHORTMEDIUM; SHORT_TOP-MEDIUM
SWD: JST-ZH6; JST_S6B-ZR-SM4A-TF(LF)(SN); MPN S6B-ZR-SM4A-TF(LF)(SN)
TEMP1, TEMP2: PAD24AWG_PAD; 24AWG_PAD
U1: MAX15062AATA+T; 21-0487A_MXM; MANUFACTURER_PART_NUMBER MAX15062BATA+T
U2: XC9265A331MR-G; SOT95P280X130-5N; MPN XC9265A331MR-G
U3: STM32G474CEU6; QFN50P700X700X60-49N; MPN STM32G474CEU6
U4: TCAN1042HGV; SOIC8; MPN TCAN1057AEVDRQ1‎
U5: AS5147; TSSOP14; MPN AS5047P-ATSM
U6: CAT25080HU4I-GT3UDFN8_2X3_ONS-M; UDFN8_2X3_ONS-M; MPN CAT24C32HU4I-GT3
U7: DRV8353S; WQFN-40; MPN DRV8353FSRTAR
VN: PAD16AWG_TERM; 16AWG_TERM
VP: PAD16AWG_TERM; 16AWG_TERM

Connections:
+3V3: AUX1.2, AUX2.2, C6.P$1, C7.P$1, C8.P$1, C10.P$1, C11.P$1, C12.P$1, C13.P$2, C15.P$1, C17.P$1, C23.P$1, C38.P$2, D33.P$1, L2.1, R2.P$2, R17.P$1, R20.P$1, R21.P$1, R25.P$1, R26.P$1, SWD.6, TEMP1.P$1, U2.4 (VOUT), U3.1 (VBAT), U3.20 (VREF+), U3.21 (VDDA), U3.23 (VDD_1), U3.35 (VDD_2), U3.48 (VDD_3), U4.5 (VIO), U5.12 (VDD3V), U6.3 (!WP), U6.7 (!HOLD), U6.8 (VCC), U7.24 (VREF)
+5V: AUX1.1, AUX2.1, C4.P$1, C5.P$1, C14.P$1, C16.P$1, C22.P$1, D50.P$1, L1.1, U1.4 (FB/VOUT), U2.1 (VIN), U2.3 (CE), U4.3 (VCC)
AS5047_CS: U3.42 (PB4), U5.1 (CS/)
AS5047_MISO: C26.P$1, R12.P$2, U3.40 (PC11), U5.3 (MISO)
AS5047_MOSI: C25.P$1, R13.P$2, U3.43 (PB5), U5.4 (MOSI)
AS5047_SCK: C24.P$1, R14.P$2, U3.39 (PC10), U5.2 (CLK)
AUX_SC1: C20.P$1, R5.P$2, U3.27 (PB14)
AUX_SC2: C21.P$1, R4.P$2, U3.28 (PB15)
AUX_SCL: C19.P$1, R9.P$2, U3.46 (PB8-BOOT0)
AUX_SDA: C18.P$1, R8.P$2, U3.26 (PB13), U3.47 (PB9)
CAN_N: CAN1.2, CAN2.2, U4.6 (CANL)
CAN_P: CAN1.1, CAN2.1, U4.7 (CANH)
CAN_RX: U3.33 (PA11), U4.4 (RXD)
CAN_TX: U3.34 (PA12), U4.1 (TXD)
CUR1: R22.P$1, U7.23 (SOA)
CUR2: R23.P$1, U7.22 (SOB)
CUR3: R24.P$1, U7.21 (SOC)
DAC: DAC.P$1, R2.P$1, R3.P$2, U3.12 (PA4)
DEBUG_RX: DTR.P$1, U3.45 (PB7)
DEBUG_TX: DTX.P$1, U3.44 (PB6)
DRV8323_CS: U3.17 (PB0), U7.30 (CS)
DRV8323_MISO: R25.P$2, U3.14 (PA6), U6.2 (SO), U7.27 (MISO)
DRV8323_MOSI: U3.15 (PA7), U6.5 (SI), U7.28 (MOSI)
DRV8323_SCLK: U3.13 (PA5), U6.6 (SCK), U7.29 (SCLK)
EEPROM_CS: U3.38 (PA15), U6.1 (!CS)
FCUR1: C30.P$1, R22.P$2, U3.11 (PA3)
FCUR2: C31.P$1, R23.P$2, U3.16 (PC4)
FCUR3: C32.P$1, R24.P$2, U3.18 (PB1)
GHA: D5.1 (K), R28.P$1, U7.6 (GHA)
GHA_D: D5.2 (A), Q1.4 (G), R28.P$2
GHB: D8.1 (K), R30.P$1, U7.15 (GHB)
GHB_D: D8.2 (A), Q3.4 (G), R30.P$2
GHC: D11.1 (K), R32.P$1, U7.16 (GHC)
GHC_D: D11.2 (A), Q5.4 (G), R32.P$2
GLA: D3.1 (K), R27.P$1, U7.8 (GLA)
GLA_D: D3.2 (A), D4.1 (K), Q2.4 (G), R27.P$2
GLB: D6.1 (K), R29.P$1, U7.13 (GLB)
GLB_D: D6.2 (A), D7.1 (K), Q4.4 (G), R29.P$2
GLC: D9.1 (K), R31.P$1, U7.18 (GLC)
GLC_D: D9.2 (A), D10.1 (K), Q6.4 (G), R31.P$2
GND: AUX1.8, AUX2.7, C3.P$2, C4.P$2, C5.P$2, C6.P$2, C7.P$2, C8.P$2, C9.P$2, C10.P$2, C11.P$2, C12.P$2, C13.P$1, C14.P$2, C15.P$2, C16.P$2, C17.P$2, C18.P$2, C19.P$2, C20.P$2, C21.P$2, C22.P$2, C23.P$2, C24.P$2, C25.P$2, C26.P$2, C27.P$2, C28.P$2, C29.P$2, C30.P$2, C31.P$2, C32.P$2, C38.P$1, CAN1.3, CAN2.3, DG1.P$1, R3.P$1, R16.P$1, R18.P$2, R19.P$2, SH4.2, SWD.4, U1.7 (GND), U2.2 (GND), U3.49 (THERMALPAD), U4.2 (GND), U4.8 (STB), U5.5 (TEST), U5.13 (GND), U6.4 (VSS), U7.25 (AGND)
I2C_PULLUP: R6.P$1, R7.P$1, U3.41 (PB3)
LED1: D1.CATHODE, U3.5 (PF0-OSC_IN)
LED2: D2.CATHODE, U3.6 (PF1-OSC_OUT)
MOTOR1: MOT1.P$1, U3.8 (PA0), U7.32 (INHA)
MOTOR2: MOT2.P$1, U3.9 (PA1), U7.34 (INHB)
MOTOR3: MOT3.P$1, U3.10 (PA2), U7.36 (INHC)
MOTOR_ENABLE: U3.3 (PC14-OSC32_IN), U7.31 (ENABLE)
MOTOR_FAULT: R26.P$2, U3.2 (PC13), U7.26 (FAULT)
MOTOR_HIZ: U3.4 (PC15-OSC32_OUT), U7.33 (INLA), U7.35 (INLB), U7.37 (INLC)
unnamed: C1.P$1, M3.P$1, R1.P$1
unnamed: C36.P$2, U7.40 (VGLS)
unnamed: AUX2.3, R4.P$1
unnamed: C3.P$1, U1.3 (VCC)
unnamed: L2.2, U2.5 (LX)
unnamed: AUX2.4, R5.P$1
unnamed: AUX2.6, R6.P$2, R8.P$1
unnamed: AUX2.5, R7.P$2, R9.P$1
unnamed: AUX1.3, R10.P$1
unnamed: C35.P$2, U7.1 (CPL)
unnamed: AUX1.4, R11.P$1
unnamed: AUX1.5, R12.P$1
unnamed: C35.P$1, U7.2 (CPH)
unnamed: C34.P$2, U7.5 (VCP)
unnamed: AUX1.6, R13.P$1
unnamed: C37.P$2, U7.38 (DVDD)
unnamed: D1.ANODE, R20.P$2
unnamed: D2.ANODE, R21.P$2
unnamed: AUX1.7, R14.P$1
NRST: C9.P$1, SWD.2, U3.7 (PG10-NRST)
PRIMARY_CS: R11.P$2, U3.19 (PB2)
PRIMARY_EXTRA: R10.P$2, U3.24 (PB11)
S1: AUX2.S1
S2: AUX2.S2
SHA: A.1, A.2, A.3, A.4, A.5, A.6, A.7, A.8, A.9, A.10, A.11, A.12, Q1.1 (S), Q1.2 (S), Q1.3 (S), Q2.5 (D), Q2.6 (D), Q2.7 (D), Q2.8 (D), Q2.PAD (D), U7.7 (SHA)
SHB: B.1, B.2, B.3, B.4, B.5, B.6, B.7, B.8, B.9, B.10, B.11, B.12, Q3.1 (S), Q3.2 (S), Q3.3 (S), Q4.5 (D), Q4.6 (D), Q4.7 (D), Q4.8 (D), Q4.PAD (D), U7.14 (SHB)
SHC: C.1, C.2, C.3, C.4, C.5, C.6, C.7, C.8, C.9, C.10, C.11, C.12, Q5.1 (S), Q5.2 (S), Q5.3 (S), Q6.5 (D), Q6.6 (D), Q6.7 (D), Q6.8 (D), Q6.PAD (D), U7.17 (SHC)
SWCLK: SWD.5, U3.37 (PA14)
SWDIO: SWD.3, U3.36 (PA13)
SXA_N: SH1.1, U7.10 (SNA)
SXA_P: C40.P$2, Q2.1 (S), Q2.2 (S), Q2.3 (S), RA.2, U7.9 (SPA)
SXB_N: SH2.1, U7.11 (SNB)
SXB_P: C41.P$2, Q4.1 (S), Q4.2 (S), Q4.3 (S), RB.2, U7.12 (SPB)
SXC_N: SH3.1, U7.20 (SNC)
SXC_P: C42.P$2, Q6.1 (S), Q6.2 (S), Q6.3 (S), RC.2, U7.19 (SPC)
V+: C2.P$1, C33.P$1, C34.P$1, C39.P$1, C40.P$1, C41.P$1, C42.P$1, C43.1 (+), C44.1 (+), C45.P$1, C46.P$1, C47.P$1, C48.P$1, C49.P$1, C50.P$1, C51.P$1, C52.P$1, C53.P$1, C54.P$1, C55.P$1, C56.P$1, C57.P$1, C58.P$1, C59.P$1, C60.P$1, D12.C, J1.1, J2.1, Q1.5 (D), Q1.6 (D), Q1.7 (D), Q1.8 (D), Q1.PAD (D), Q3.5 (D), Q3.6 (D), Q3.7 (D), Q3.8 (D), Q3.PAD (D), Q5.5 (D), Q5.6 (D), Q5.7 (D), Q5.8 (D), Q5.PAD (D), R15.P$2, U1.1 (VIN), U1.2 (EN/UVLO), U7.3 (VM), U7.4 (VDRAIN), VP.1, VP.2, VP.3, VP.4, VP.5, VP.6, VP.7, VP.8, VP.9, VP.10, VP.11, VP.12
V-: C1.P$2, C2.P$2, C33.P$2, C36.P$1, C37.P$1, C39.P$2, C43.2 (-), C44.2 (-), C45.P$2, C46.P$2, C47.P$2, C48.P$2, C49.P$2, C50.P$2, C51.P$2, C52.P$2, C53.P$2, C54.P$2, C55.P$2, C56.P$2, C57.P$2, C58.P$2, C59.P$2, C60.P$2, D4.2 (A), D7.2 (A), D10.2 (A), D12.A, J1.2, J2.2, R1.P$2, RA.1, RB.1, RC.1, SH1.2, SH2.2, SH3.2, SH4.1, U7.39 (GND), U7.P1 (PAD), U7.P2 (PAD), U7.P3 (PAD), U7.P7 (PAD), U7.P8 (PAD), U7.P9 (PAD), U7.P12 (PAD), U7.P13 (PAD), U7.P14 (PAD), U7.P17 (PAD), U7.P18 (PAD), U7.P19 (PAD), U7.PAD, VN.1, VN.2, VN.3, VN.4, VN.5, VN.6, VN.7, VN.8, VN.9, VN.10, VN.11, VN.12
VBAT_SENSE: C27.P$1, R15.P$1, R16.P$2, U3.31 (PA9)
VSW: L1.2, U1.8 (LX)
VTEMP_FET: C28.P$1, R17.P$2, R18.P$1, U3.25 (PB12)
VTEMP_MOT: C29.P$1, R19.P$1, TEMP2.P$1, U3.30 (PA8)

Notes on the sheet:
PCB rev divider HI / LO r1 - open / 100k



Board: 4 copper layers, 46.0 x 46.0 mm, 153 parts (82 on the bottom side), 89 nets.

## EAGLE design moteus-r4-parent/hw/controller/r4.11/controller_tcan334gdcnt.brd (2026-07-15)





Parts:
A: PAD16AWG_PAD; 16AWG_PAD
ABS: JST_ZH4; JST_S4B-ZR-SM4A-TF(LF)(SN); MPN S4B-ZR-SM4A-TF(LF)(SN)
B: PAD16AWG_PAD; 16AWG_PAD
C: PAD16AWG_PAD; 16AWG_PAD
C1, C2, C3, C5, C6, C8, C10, C12, C13, C18: 0.1uF; C0402; MPN MF-CAP-0402-0.1uF
C4, C9, C15, C17, C56: 1uF; C0402; MPN MF-CAP-0402-1uF
C7, C21: 10uF; C1206; MPN MF-CAP-1206-10uF
C11: 0.1uF; C0402_NOBORDER; MPN MF-CAP-0402-0.1uF
C14, C16: 0.1uF 50V; C0402; MPN CGA2B3X7R1H104K050BB
C19: 0.47uF 50V; C0402; MPN GRM155R61H474KE11D
C20: 1uF; C0603; MPN MF-CAP-0603-1uF
C22, C23, C24, C25, C26, C27, C28, C29, C30, C31, C32, C33, C34, C36, C37: 10uF 50V; C1206; MPN C3216X7R1H106K160AE
C35: 10uF 50V; C1206_NOBORDER; MPN C3216X7R1H106K160AE
C38: 1uF; C0603; MPN C1608X7R1E105K080AE
C39: 1uF 100V; C0805; MPN GCM21BC72A105KE36L
C40, C41, C42, C43, C44, C45, C46, C47, C48, C49, C50, C51, C52, C53, C54: DNP; C1206_NOCREAM
C55: DNP; C0402
C57: 0.01uF; C0402; MPN MF-CAP-0402-0.01uF
C58, C59, C60: 1000pF; C0402_NOBORDER; MPN MF-CAP-0402-1nF
C61, C63: 0.1uF 50V; C1206; MPN 12065C104KAZ2A
C62: 0.1uF 50V; C0603_NOBORDER; MPN 06035C104KAZ2A
CAN1, CAN2: JST-PH3; JST_S3B-PH-SM4-TB(LF)(SN); MPN S3B-PH-SM4-TB(LF)(SN)
D1, D5, D6, D7, D8, D9, D10, D11, D12: BAT41KFILM; SODFL1608X70N; MPN BAT41KFILM
D2: MF-LED-0603-RED; LED0603; MPN MF-LED-0603-GREEN
D3: MF-LED-0603-RED; LED0603
D4: DUAL_TVS; SOT23-3; MPN CDSOT23-0502B
D33: PAD24AWG_PAD; 24AWG_PAD
DA: PAD24AWG_PAD; 24AWG_PAD
DAC: PAD24AWG_PAD; 24AWG_PAD
DB: PAD24AWG_PAD; 24AWG_PAD
DBG1, DBG2: PAD24AWG_PAD; 24AWG_PAD
DC: PAD24AWG_PAD; 24AWG_PAD
DG1, DG2: PAD24AWG_PAD; 24AWG_PAD
DRV_CS: PAD24AWG_PAD; 24AWG_PAD
DRV_MISO: PAD24AWG_PAD; 24AWG_PAD
DRV_MOSI: PAD24AWG_PAD; 24AWG_PAD
DRV_SCK: PAD24AWG_PAD; 24AWG_PAD
DTR: PAD24AWG_PAD; 24AWG_PAD
DTX: PAD24AWG_PAD; 24AWG_PAD
ENC: PICO-SPOX-6NOPASTE; PICO-SPOX-SMT-RA-6-NOPASTE
J1, J2: XT30XT30PW_MALE; XT30PW_MALE
L1: SRN4018-220M; IND_BOURNS_SRN4018; MANUFACTURER_PART_NUMBER SRN4018-330M
L2, L3: HALF_CHOKE; 1812_COMMON_HALF; MPN MF-RES-0805-0
M1, M2, M3, M4: MOUNT; M2.5MOUNT
MOT1, MOT2, MOT3: PAD24AWG_PAD; 24AWG_PAD
Q1, Q2, Q3, Q4, Q5, Q6: TPH1R204PLSOP_ADVANCE_8; SOP_ADVANCE_8; MPN TPH2R506PL,L1Q
R1, R2: 560; R0402; MPN MF-RES-0402-560
R3, R4, R13, R14: 2k; R0402; MPN MF-RES-0402-2K
R5: 100k 1%; R0402; MPN RC0402FR-07100KL
R6: 4.7k 1%; R0402; MPN RC0402FR-074K7L
R7, R9: 10k 1%; R0402; MPN RC0402FR-0710KL
R8: 47k NTC; R0402; MPN NCP15WB473F03RC
R10: DNP; R0402
R15, R16, R17: 22; R0402_NOBORDER; MPN MF-RES-0402-22
R22, R23, R24, R25, R26, R27: 7.5; R0402; MPN RC0402FR-077R5L
RA: 0.5mOhm 1% 2W; M1206; MPN HCS1206FTL500
RB: 0.5mOhm 1% 2W; M1206; MPN HCS1206FTL500
RC: 0.5mOhm 1% 2W; M1206; MPN HCS1206FTL500
SH1, SH2, SH3: SHORTT5; SHORT_TOP-50
SH4: SHORTMEDIUM; SHORT_TOP-MEDIUM
SWD: JST-ZH6; JST_S6B-ZR-SM4A-TF(LF)(SN); MPN S6B-ZR-SM4A-TF(LF)(SN)
TEMP1, TEMP2: PAD24AWG_PAD; 24AWG_PAD
U1: STM32G474CEU6; QFN50P700X700X60-49N; MPN STM32G474CEU6
U2: TCAN334G; SOIC8; MPN TCAN337GDR
U3: AS5147; TSSOP14; MPN AS5047P-ATSM
U4: MAX15062AATA+T; 21-0487A_MXM; MPN MAX15062AATA+T
U5: DRV8353S; WQFN-40; MPN DRV8353FSRTAR
U6: TCAN334GSOT23; SOT23-8; MPN TCAN334GDCNT

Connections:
+3V3: ABS.1, C1.P$1, C2.P$1, C4.P$1, C5.P$1, C6.P$1, C7.P$2, C8.P$1, C9.P$1, C10.P$1, C11.P$1, C12.P$1, C18.P$2, C21.P$1, C56.P$1, D33.P$1, ENC.1, L1.1, R1.P$1, R2.P$1, R3.P$1, R4.P$1, R8.P$1, R13.P$1, R14.P$1, SWD.6, TEMP1.P$1, U1.1 (VBAT), U1.20 (VREF+), U1.21 (VDDA), U1.23 (VDD_1), U1.35 (VDD_2), U1.48 (VDD_3), U2.3 (VCC), U3.12 (VDD3V), U4.4 (FB/VOUT), U5.24 (VREF), U6.3 (VCC)
AS5047_A: U1.43 (PB5), U3.7 (A)
AS5047_B: U1.42 (PB4), U3.6 (B)
AS5047_CS: U1.24 (PB11), U3.1 (CS/)
AS5047_MISO: ENC.5, U1.27 (PB14), U3.3 (MISO)
AS5047_MOSI: ENC.6, U1.28 (PB15), U3.4 (MOSI)
AS5047_SCK: ENC.4, U1.26 (PB13), U3.2 (CLK)
CAN2_N: L2.P$2 (2), U2.6 (CANL), U6.6 (CANL)
CAN2_P: L3.P$2 (2), U2.7 (CANH), U6.7 (CANH)
CAN_N: CAN1.2, CAN2.2, D4.2, L2.P$1 (1)
CAN_P: CAN1.1, CAN2.1, D4.1, L3.P$1 (1)
CAN_RX: U1.33 (PA11), U2.4 (RXD), U6.4 (RXD)
CAN_TX: U1.34 (PA12), U2.1 (TXD), U6.1 (TXD)
CUR1: R15.P$1, U5.23 (SOA)
CUR2: R16.P$1, U5.22 (SOB)
CUR3: R17.P$1, U5.21 (SOC)
DAC: DAC.P$1, U1.12 (PA4)
DEBUG1: DBG1.P$1, U1.3 (PC14-OSC32_IN)
DEBUG2: DBG2.P$1, U1.4 (PC15-OSC32_OUT)
DEBUG_RX: DTR.P$1, U1.40 (PC11)
DEBUG_TX: DTX.P$1, U1.39 (PC10)
DRV8323_CS: DRV_CS.P$1, U1.16 (PC4), U5.30 (CS)
DRV8323_MISO: DRV_MISO.P$1, R13.P$2, U1.14 (PA6), U5.27 (MISO)
DRV8323_MOSI: DRV_MOSI.P$1, U1.15 (PA7), U5.28 (MOSI)
DRV8323_SCLK: DRV_SCK.P$1, U1.13 (PA5), U5.29 (SCLK)
FCUR1: C58.P$1, R15.P$2, U1.17 (PB0)
FCUR2: C59.P$1, R16.P$2, U1.18 (PB1)
FCUR3: C60.P$1, R17.P$2, U1.19 (PB2)
GHA: D10.1 (K), R22.P$1, U5.6 (GHA)
GHA_D: D10.2 (A), Q1.4 (G), R22.P$2
GHB: D11.1 (K), R24.P$1, U5.15 (GHB)
GHB_D: D11.2 (A), Q3.4 (G), R24.P$2
GHC: D12.1 (K), R26.P$1, U5.16 (GHC)
GHC_D: D12.2 (A), Q5.4 (G), R26.P$2
GLA: D7.1 (K), R23.P$1, U5.8 (GLA)
GLA_D: D1.1 (K), D7.2 (A), Q2.4 (G), R23.P$2
GLB: D8.1 (K), R25.P$1, U5.13 (GLB)
GLB_D: D5.1 (K), D8.2 (A), Q4.4 (G), R25.P$2
GLC: D9.1 (K), R27.P$1, U5.18 (GLC)
GLC_D: D6.1 (K), D9.2 (A), Q6.4 (G), R27.P$2
GND: ABS.4, C1.P$2, C2.P$2, C3.P$2, C4.P$2, C5.P$2, C6.P$2, C7.P$1, C8.P$2, C9.P$2, C10.P$2, C11.P$2, C12.P$2, C13.P$2, C18.P$1, C20.P$2, C21.P$2, C56.P$2, C57.P$2, C58.P$2, C59.P$2, C60.P$2, CAN1.3, CAN2.3, D4.3, DG1.P$1, DG2.P$1, ENC.3, R6.P$1, R7.P$2, R9.P$2, SH4.2, SWD.4, U1.32 (PA10), U1.49 (THERMALPAD), U2.2 (GND), U2.5 (SHDN), U2.8 (STB), U3.5 (TEST), U3.13 (GND), U4.7 (GND), U5.25 (AGND), U6.2 (GND), U6.5 (SHDN), U6.8 (STB)
I2C_ABS_SCL: ABS.2, R4.P$2, U1.46 (PB8-BOOT0)
I2C_ABS_SDA: ABS.3, R3.P$2, U1.47 (PB9)
LED1: D3.CATHODE, U1.5 (PF0-OSC_IN)
LED2: D2.CATHODE, U1.6 (PF1-OSC_OUT)
MOTOR1: MOT1.P$1, U1.8 (PA0), U5.32 (INHA)
MOTOR2: MOT2.P$1, U1.9 (PA1), U5.34 (INHB)
MOTOR3: MOT3.P$1, U1.10 (PA2), U5.36 (INHC)
MOTOR_ENABLE: U1.11 (PA3), U5.31 (ENABLE)
MOTOR_FAULT: R14.P$2, U1.44 (PB6), U5.26 (FAULT)
MOTOR_HIZ: U1.45 (PB7), U5.33 (INLA), U5.35 (INLB), U5.37 (INLC)
unnamed: C55.P$1, M3.P$1, R10.P$1
unnamed: C38.P$2, U5.40 (VGLS)
unnamed: C20.P$1, U4.3 (VCC)
unnamed: C16.P$2, U5.1 (CPL)
unnamed: C16.P$1, U5.2 (CPH)
unnamed: C15.P$2, U5.5 (VCP)
unnamed: C17.P$2, U5.38 (DVDD)
unnamed: D3.ANODE, R1.P$2
unnamed: D2.ANODE, R2.P$2
NRST: C3.P$1, SWD.2, U1.7 (PG10-NRST)
SECONDARY_ENC_CS: ENC.2, U1.2 (PC13)
SHA: A.1, DA.P$1, Q1.1 (S), Q1.2 (S), Q1.3 (S), Q2.5 (D), Q2.6 (D), Q2.7 (D), Q2.8 (D), Q2.PAD (D), U5.7 (SHA)
SHB: B.1, DB.P$1, Q3.1 (S), Q3.2 (S), Q3.3 (S), Q4.5 (D), Q4.6 (D), Q4.7 (D), Q4.8 (D), Q4.PAD (D), U5.14 (SHB)
SHC: C.1, DC.P$1, Q5.1 (S), Q5.2 (S), Q5.3 (S), Q6.5 (D), Q6.6 (D), Q6.7 (D), Q6.8 (D), Q6.PAD (D), U5.17 (SHC)
SWCLK: SWD.5, U1.37 (PA14)
SWDIO: SWD.3, U1.36 (PA13)
SXA_N: SH1.1, U5.10 (SNA)
SXA_P: C61.P$2, Q2.1 (S), Q2.2 (S), Q2.3 (S), RA.2, U5.9 (SPA)
SXB_N: SH2.1, U5.11 (SNB)
SXB_P: C62.P$2, Q4.1 (S), Q4.2 (S), Q4.3 (S), RB.2, U5.12 (SPB)
SXC_N: SH3.1, U5.20 (SNC)
SXC_P: C63.P$2, Q6.1 (S), Q6.2 (S), Q6.3 (S), RC.2, U5.19 (SPC)
V+: C14.P$1, C15.P$1, C19.P$1, C22.P$1, C23.P$1, C24.P$1, C25.P$1, C26.P$1, C27.P$1, C28.P$1, C29.P$1, C30.P$1, C31.P$1, C32.P$1, C33.P$1, C34.P$1, C35.P$1, C36.P$1, C37.P$1, C39.P$1, C40.P$1, C41.P$1, C42.P$1, C43.P$1, C44.P$1, C45.P$1, C46.P$1, C47.P$1, C48.P$1, C49.P$1, C50.P$1, C51.P$1, C52.P$1, C53.P$1, C54.P$1, C61.P$1, C62.P$1, C63.P$1, J1.1, J2.1, Q1.5 (D), Q1.6 (D), Q1.7 (D), Q1.8 (D), Q1.PAD (D), Q3.5 (D), Q3.6 (D), Q3.7 (D), Q3.8 (D), Q3.PAD (D), Q5.5 (D), Q5.6 (D), Q5.7 (D), Q5.8 (D), Q5.PAD (D), R5.P$2, U4.1 (VIN), U4.2 (EN/UVLO), U5.3 (VM), U5.4 (VDRAIN)
V-: C14.P$2, C17.P$1, C19.P$2, C22.P$2, C23.P$2, C24.P$2, C25.P$2, C26.P$2, C27.P$2, C28.P$2, C29.P$2, C30.P$2, C31.P$2, C32.P$2, C33.P$2, C34.P$2, C35.P$2, C36.P$2, C37.P$2, C38.P$1, C39.P$2, C40.P$2, C41.P$2, C42.P$2, C43.P$2, C44.P$2, C45.P$2, C46.P$2, C47.P$2, C48.P$2, C49.P$2, C50.P$2, C51.P$2, C52.P$2, C53.P$2, C54.P$2, C55.P$2, D1.2 (A), D5.2 (A), D6.2 (A), J1.2, J2.2, R10.P$2, RA.1, RB.1, RC.1, SH1.2, SH2.2, SH3.2, SH4.1, U5.39 (GND), U5.P1 (PAD), U5.P2 (PAD), U5.P3 (PAD), U5.P7 (PAD), U5.P8 (PAD), U5.P9 (PAD), U5.P12 (PAD), U5.P13 (PAD), U5.P14 (PAD), U5.P17 (PAD), U5.P18 (PAD), U5.P19 (PAD), U5.PAD
VBAT_SENSE: C57.P$1, R5.P$1, R6.P$2, U1.25 (PB12)
VSW: L1.2, U4.8 (LX)
VTEMP_FET: C13.P$1, R8.P$2, R9.P$1, U1.31 (PA9)
VTEMP_MOT: R7.P$1, TEMP2.P$1, U1.30 (PA8)

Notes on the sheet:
PA10/PA15/PC6 Version 011
L2/L3 SIZED TO HOLD EITHER A) 2x 0805 0 OHM RESISTORS B) A COILCRAFT 1812CAN SERIES COMMON MODE CHOKE
ALTERNATE PARTS CAN USE SOIC-8 OR SOT-23 FOOTPRINTS



Board: 4 copper layers, 46.0 x 53.0 mm, 152 parts (23 on the bottom side), 79 nets.

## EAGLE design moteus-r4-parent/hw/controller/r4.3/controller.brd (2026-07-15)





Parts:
A: PAD; 18AWG_PAD
ABS: JST_ZH4; JST_S4B-ZR-SM4A-TF(LF)(SN); MPN S4B-ZR-SM4A-TF(LF)(SN)
B: PAD; 18AWG_PAD
C: PAD; 18AWG_PAD
C1, C2, C3, C5, C6, C8, C10, C11, C12, C13, C18: 0.1uF; C0402; MPN MF-CAP-0402-0.1uF
C4, C9, C15, C17: 1uF; C0402; MPN MF-CAP-0402-1uF
C7, C21: 10uF; C1206; MPN MF-CAP-1206-10uF
C14, C16, C20: 0.1uF 50V; C0402; MPN CGA2B3X7R1H104K050BB
C19: 0.47uF 50V; C0402; MPN UMK105ABJ474KV-F
C22, C23, C24, C25, C26, C27, C28, C29, C30, C31, C32, C33, C34, C35, C36, C37: 10uF; C1206; MPN CGA5L1X7R1H106K160AC
CAN1, CAN2: JST-PH3; JST_S3B-PH-SM4-TB(LF)(SN); MPN S3B-PH-SM4-TB(LF)(SN)
D1: MF-DIO-SMA-B140; SMA
D2: MF-LED-0603-RED; LED0603; MPN MF-LED-0603-GREEN
D3: MF-LED-0603-RED; LED0603
D33: PAD24AWG_PAD; 24AWG_PAD
DA: PAD24AWG_PAD; 24AWG_PAD
DAC: PAD24AWG_PAD; 24AWG_PAD
DB: PAD24AWG_PAD; 24AWG_PAD
DBG1, DBG2: PAD24AWG_PAD; 24AWG_PAD
DC: PAD24AWG_PAD; 24AWG_PAD
DG1, DG2: PAD24AWG_PAD; 24AWG_PAD
DRV_CS: PAD24AWG_PAD; 24AWG_PAD
DRV_MISO: PAD24AWG_PAD; 24AWG_PAD
DRV_MOSI: PAD24AWG_PAD; 24AWG_PAD
DRV_SCK: PAD24AWG_PAD; 24AWG_PAD
DTR: PAD24AWG_PAD; 24AWG_PAD
DTX: PAD24AWG_PAD; 24AWG_PAD
J1, J2: XT30XT30PW_MALE; XT30PW_MALE
L1: SRN4018-220M; IND_BOURNS_SRN4018; MPN SRN4018-220M
M1, M2, M3, M4: MOUNT; M2.5MOUNT
MOT1, MOT2, MOT3: PAD24AWG_PAD; 24AWG_PAD
Q1, Q2, Q3, Q4, Q5, Q6: TPH1R204PLSOP_ADVANCE_8; SOP_ADVANCE_8; MPN TPH1R204PL,L1Q
R1, R2: 560; R0402; MPN MF-RES-0402-560
R3, R4, R13, R14: 2k; R0402; MPN MF-RES-0402-2K
R5, R10: 100k 1%; R0402; MPN ERJ-2RKF1003X
R6, R7, R9, R12: 10k 1%; R0402; MPN ERJ-2RKF1002X
R8: 47k NTC; R0402; MPN NCP15WB473F03RC
R11: 33k 1%; R0402; MPN ERJ-2RKF3302X
RA: 0.5mOhm 1% 2W; M1206; MPN HCS1206FTL500
RB: 0.5mOhm 1% 2W; M1206; MPN HCS1206FTL500
RC: 0.5mOhm 1% 2W; M1206; MPN HCS1206FTL500
SH1, SH2, SH3: SHORTT5; SHORT_TOP-50
SH4: SHORTBIG; SHORT_TOP-BIG
SWD: JST-ZH6; JST_S6B-ZR-SM4A-TF(LF)(SN); MPN S6B-ZR-SM4A-TF(LF)(SN)
TEMP1, TEMP2: PAD24AWG_PAD; 24AWG_PAD
U1: STM32G474CEU6; QFN50P700X700X60-49N; MPN STM32G474CEU6
U2: TCAN334GSOT23; SOT23-8; MPN TCAN334GDCNT
U3: AS5147; TSSOP14; MPN AS5047P-ATSM
U4: DRV8323RS; PVQFN-N48; MPN DRV8323RSRGZR

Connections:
+3V3: ABS.1, C1.P$1, C2.P$1, C4.P$1, C5.P$1, C6.P$1, C7.P$2, C8.P$1, C9.P$1, C10.P$1, C11.P$1, C12.P$1, C18.P$2, C21.P$1, D33.P$1, L1.1, R1.P$1, R2.P$1, R3.P$1, R4.P$1, R8.P$1, R11.P$1, R13.P$1, R14.P$1, SWD.6, TEMP1.P$1, U1.1 (VBAT), U1.20 (VREF+), U1.21 (VDDA), U1.23 (VDD_1), U1.35 (VDD_2), U1.48 (VDD_3), U2.3 (VCC), U3.12 (VDD3V), U4.26 (VREF)
AS5047_A: U1.43 (PB5), U3.7 (A)
AS5047_B: U1.42 (PB4), U3.6 (B)
AS5047_CS: U1.24 (PB11), U3.1 (CS/)
AS5047_MISO: U1.27 (PB14), U3.3 (MISO)
AS5047_MOSI: U1.28 (PB15), U3.4 (MOSI)
AS5047_SCK: U1.26 (PB13), U3.2 (CLK)
CAN_N: CAN1.2, CAN2.2, U2.6 (CANL)
CAN_P: CAN1.1, CAN2.1, U2.7 (CANH)
CAN_RX: U1.33 (PA11), U2.4 (RXD)
CAN_TX: U1.34 (PA12), U2.1 (TXD)
CUR1: U1.17 (PB0), U4.25 (SOA)
CUR2: U1.18 (PB1), U4.24 (SOB)
CUR3: U1.19 (PB2), U4.23 (SOC)
DAC: DAC.P$1, U1.12 (PA4)
DEBUG1: DBG1.P$1, U1.3 (PC14-OSC32_IN)
DEBUG2: DBG2.P$1, U1.4 (PC15-OSC32_OUT)
DEBUG_RX: DTR.P$1, U1.40 (PC11)
DEBUG_TX: DTX.P$1, U1.39 (PC10)
DRV8323_CS: DRV_CS.P$1, U1.16 (PC4), U4.32 (CS)
DRV8323_MISO: DRV_MISO.P$1, R13.P$2, U1.14 (PA6), U4.29 (MISO)
DRV8323_MOSI: DRV_MOSI.P$1, U1.15 (PA7), U4.30 (MOSI)
DRV8323_SCLK: DRV_SCK.P$1, U1.13 (PA5), U4.31 (SCLK)
GHA: Q1.4 (G), U4.8 (GHA)
GHB: Q3.4 (G), U4.17 (GHB)
GHC: Q5.4 (G), U4.18 (GHC)
GLA: Q2.4 (G), U4.10 (GLA)
GLB: Q4.4 (G), U4.15 (GLB)
GLC: Q6.4 (G), U4.20 (GLC)
GND: ABS.4, C1.P$2, C2.P$2, C3.P$2, C4.P$2, C5.P$2, C6.P$2, C7.P$1, C8.P$2, C9.P$2, C10.P$2, C11.P$2, C12.P$2, C13.P$2, C17.P$1, C18.P$1, C21.P$2, CAN1.3, CAN2.3, DG1.P$1, DG2.P$1, R6.P$1, R7.P$2, R9.P$2, SH4.2, SWD.4, U1.49 (THERMALPAD), U2.2 (GND), U2.5 (SHDN), U2.8 (STB), U3.5 (TEST), U3.13 (GND), U4.27 (DGND), U4.35 (AGND)
I2C_ABS_SCL: ABS.2, R4.P$2, U1.46 (PB8-BOOT0), U1.47 (PB9)
I2C_ABS_SDA: ABS.3, R3.P$2
LED1: D3.CATHODE, U1.5 (PF0-OSC_IN)
LED2: D2.CATHODE, U1.6 (PF1-OSC_OUT)
MOTOR1: MOT1.P$1, U1.8 (PA0), U4.37 (INHA)
MOTOR2: MOT2.P$1, U1.9 (PA1), U4.39 (INHB)
MOTOR3: MOT3.P$1, U1.10 (PA2), U4.41 (INHC)
MOTOR_ENABLE: U1.11 (PA3), U4.33 (ENABLE)
MOTOR_FAULT: R14.P$2, U1.44 (PB6), U4.28 (FAULT)
MOTOR_HIZ: U1.45 (PB7), U4.38 (INLA), U4.40 (INLB), U4.42 (INLC)
unnamed: R10.P$1, U4.48 (SHDN)
unnamed: R11.P$2, R12.P$1, U4.1 (FB)
unnamed: C16.P$2, U4.3 (CPL)
unnamed: C20.P$2, D1.CATHODE, L1.2, U4.45 (SW)
unnamed: C20.P$1, U4.44 (CB)
unnamed: C16.P$1, U4.4 (CPH)
unnamed: C15.P$2, U4.5 (VCP)
unnamed: C17.P$2, U4.36 (DVDD)
unnamed: D3.ANODE, R1.P$2
unnamed: D2.ANODE, R2.P$2
NRST: C3.P$1, SWD.2, U1.7 (PG10-NRST)
SHA: A.1, DA.P$1, Q1.1 (S), Q1.2 (S), Q1.3 (S), Q2.5 (D), Q2.6 (D), Q2.7 (D), Q2.8 (D), Q2.PAD (D), U4.9 (SHA)
SHB: B.1, DB.P$1, Q3.1 (S), Q3.2 (S), Q3.3 (S), Q4.5 (D), Q4.6 (D), Q4.7 (D), Q4.8 (D), Q4.PAD (D), U4.16 (SHB)
SHC: C.1, DC.P$1, Q5.1 (S), Q5.2 (S), Q5.3 (S), Q6.5 (D), Q6.6 (D), Q6.7 (D), Q6.8 (D), Q6.PAD (D), U4.19 (SHC)
SNA: SH1.1, U4.12 (SNA)
SNB: SH2.1, U4.13 (SNB)
SNC: SH3.1, U4.22 (SNC)
SPA: Q2.1 (S), Q2.2 (S), Q2.3 (S), RA.2, U4.11 (SPA)
SPB: Q4.1 (S), Q4.2 (S), Q4.3 (S), RB.2, U4.14 (SPB)
SPC: Q6.1 (S), Q6.2 (S), Q6.3 (S), RC.2, U4.21 (SPC)
SWCLK: SWD.5, U1.37 (PA14)
SWDIO: SWD.3, U1.36 (PA13)
V+: C14.P$1, C15.P$1, C19.P$1, C22.P$1, C23.P$1, C24.P$1, C25.P$1, C26.P$1, C27.P$1, C28.P$1, C29.P$1, C30.P$1, C31.P$1, C32.P$1, C33.P$1, C34.P$1, C35.P$1, C36.P$1, C37.P$1, J1.1, J2.1, Q1.5 (D), Q1.6 (D), Q1.7 (D), Q1.8 (D), Q1.PAD (D), Q3.5 (D), Q3.6 (D), Q3.7 (D), Q3.8 (D), Q3.PAD (D), Q5.5 (D), Q5.6 (D), Q5.7 (D), Q5.8 (D), Q5.PAD (D), R5.P$2, R10.P$2, U4.6 (VM), U4.7 (VDRAIN), U4.47 (VIN)
V-: C14.P$2, C19.P$2, C22.P$2, C23.P$2, C24.P$2, C25.P$2, C26.P$2, C27.P$2, C28.P$2, C29.P$2, C30.P$2, C31.P$2, C32.P$2, C33.P$2, C34.P$2, C35.P$2, C36.P$2, C37.P$2, D1.ANODE, J1.2, J2.2, R12.P$2, RA.1, RB.1, RC.1, SH1.2, SH2.2, SH3.2, SH4.1, U4.2 (PGND), U4.43 (BGND), U4.P1 (PAD), U4.P2 (PAD), U4.P3 (PAD), U4.P4 (PAD), U4.P5 (PAD), U4.P6 (PAD), U4.P7 (PAD), U4.P8 (PAD), U4.P9 (PAD), U4.P10 (PAD), U4.P11 (PAD), U4.P12 (PAD), U4.P13 (PAD), U4.P14 (PAD), U4.P15 (PAD), U4.P16 (PAD), U4.P17 (PAD), U4.P18 (PAD), U4.P19 (PAD), U4.P20 (PAD), U4.P21 (PAD), U4.P22 (PAD), U4.P23 (PAD), U4.P24 (PAD), U4.P25 (PAD), U4.PAD
VBAT_SENSE: R5.P$1, R6.P$2, U1.30 (PA8)
VTEMP_FET: C13.P$1, R8.P$2, R9.P$1, U1.31 (PA9)
VTEMP_MOT: R7.P$1, TEMP2.P$1, U1.25 (PB12)



Board: 4 copper layers, 46.0 x 53.0 mm, 105 parts (8 on the bottom side), 67 nets.

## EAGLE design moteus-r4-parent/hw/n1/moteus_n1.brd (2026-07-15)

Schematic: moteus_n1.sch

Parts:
A: PAD16AWG_TERM; 16AWG_TERM
AUX1: SM08B-GHS-TB(LF)(SN); JST_SM08B-GHS-TB(LF)(SN); MPN SM08B-GHS-TB(LF)(SN)
AUX2: SM07B-GHS-TB(LF)(SN); JST_SM07B-GHS-TB(LF)(SN); MPN SM07B-GHS-TB(LF)(SN)
AUX2H: PH2X4
B: PAD16AWG_TERM; 16AWG_TERM
C: PAD16AWG_TERM; 16AWG_TERM
C1, C19, C20, C21, C22, C25, C26, C27, C28, C29: DNP; C0402
C2: 1uF 100V; C0805; MPN GCM21BC72A105KE36L
C3, C17, C18, C23\, C24: 1uF; C0603; MPN MF-CAP-0603-1uF
C4: 22uF; C1206; MPN GRM31CR71A226KE15L
C5, C11, C23, C41: 1uF; C0402; MPN MF-CAP-0402-1uF
C6: 22uF; C1206; MPN CL31B226KPHNNNE
C7, C8, C9, C12, C14, C15, C16, C30, C32, C33, C42, C87: 0.1uF; C0402; MPN MF-CAP-0402-0.1uF
C10: 4.7uF; C0603; MPN CL10A475KP8NNNC
C13: 10uF; C1206; MPN MF-CAP-1206-10uF
C31: 0.01uF; C0402; MPN MF-CAP-0402-0.01uF
C34, C35, C36: 1000pF; C0402; MPN MF-CAP-0402-1nF
C37, C39: 0.1uF 100V; C0603; MPN GCJ188R72A104KA01D
C38, C40: 1uF; C0603; MPN C1608X7R1E105K080AE
C43: 0.47uF 100V; C0805; MPN 08051C474KAT2A
C44, C45, C46: 0.1uF 100V; C1206; MPN 12061C104KAT2A
C47, C48: 4.7uF 100V; C1206; MPN GRJ31CC72A475KE01K
C49, C50, C51, C52, C53, C54, C55, C56, C57, C58, C59, C60, C61, C62, C63, C64, C65, C66, C67, C68, C69, C70, C71, C72, C73, C74, C75, C76, C77, C78, C79, C80, C81, C82, C83, C84, C85, C86: 4.7uF 100V; C1206_NOBORDER; MPN GRJ31CC72A475KE01K
CAN1, CAN2: JST-PH3; JST_S3B-PH-SM4-TB(LF)(SN); MPN S3B-PH-SM4-TB(LF)(SN)
CAN_DBG: 1X3
D1: MF-LED-0603-RED; LED0603
D2: MF-LED-0603-RED; LED0603; MPN MF-LED-0603-GREEN
D3, D4, D5, D6, D7, D8, D9, D10, D11, D13, D14, D15, D16: BAT41KFILM; SODFL1608X70N; MPN BAT41KFILM
D12: DIODE-DO214AA; DO214AA; MPN SMBJ51D-M3/I
D33, D50: PAD24AWG_PAD; 24AWG_PAD
DAC: PAD24AWG_PAD; 24AWG_PAD
DG1: PAD24AWG_PAD; 24AWG_PAD
DTR: PAD24AWG_PAD; 24AWG_PAD
DTX: PAD24AWG_PAD; 24AWG_PAD
J1, J2: XT30XT30PW_MALE; XT30PW_MALE; MPN XT30PW-M
J3: SM06B-GHS-TB(LF)(SN); JST_SM06B-GHS-TB(LF)(SN); MPN SM06B-GHS-TB(LF)(SN)
L1: SRN4018-220M; IND_BOURNS_SRN4018; MANUFACTURER_PART_NUMBER 74404042470
L2: 74479887222A; IND_1008_WE-PMI_WRE; MPN 74479887222A
M1, M2, M3, M4: MOUNT; M2.5MOUNT
Q1, Q3, Q5: TPH1R204PL_VIAS; SOP_ADVANCE_8_VIAS; MPN TPH2R408QM,L1Q
Q2, Q4, Q6: TPH1R204PLSOP_ADVANCE_8; SOP_ADVANCE_8; MPN TPH2R408QM,L1Q
R1, R3: DNP; R0402
R2, R15: 100k 1%; R0402; MPN RC0402FR-07100KL
R4, R5, R8, R9, R10, R11, R12, R13, R14: 100; R0402; MPN MF-RES-0402-100
R6, R7, R25, R26, R33, R34: 2k; R0402; MPN MF-RES-0402-2K
R16: 4.7k 1%; R0402; MPN RC0402FR-074K7L
R17: 47k NTC; R0402; MPN NCP15WB473F03RC
R18, R19: 10k 1%; R0402; MPN RC0402FR-0710KL
R20, R21: 560; R0402; MPN MF-RES-0402-560
R22, R23, R24: 22; R0402; MPN MF-RES-0402-22
R27, R28, R30, R31, R32: 7.5; R0402; MPN RC0402FR-077R5L
R29: 7.5; R0805; MPN RC0805FR-077R5L
R35, R36: 120; R0402; MPN RC0402FR-07120RL
R37: DNP; R0805
R38, R39, R40: 0; R0402; MPN MF-RES-0402-0
RA: 0.5mOhm 1% 2W; M1206; MPN HCS1206FTL500
RB: 0.5mOhm 1% 2W; M1206; MPN HCS1206FTL500
RC: 0.5mOhm 1% 2W; M1206; MPN HCS1206FTL500
SH1, SH2, SH3: SHORTT5; SHORT_TOP-50
SH4: SHORTMEDIUM; SHORT_TOP-MEDIUM
SWD: JST-ZH6; JST_S6B-ZR-SM4A-TF(LF)(SN); MPN S6B-ZR-SM4A-TF(LF)(SN)
TEMP: 1X2
U1: MAX15062BATA+T; 21-0487A_MXM; MANUFACTURER_PART_NUMBER MAX15062BATA+T
U2: ADP5301ACBZ-4-R7; BGA9C50P3X3_165X187X66; MPN ADP5301ACBZ-4-R7
U3: STM32G474CEU6; QFN50P700X700X60-49N; MPN STM32G474CEU6
U4: TCAN1042HGV; SOIC8; MPN TCAN1057AEVDRQ1
U5: AS5147; TSSOP14; MPN AS5047P-ATSM
U7: DRV8353S; WQFN-40; MPN DRV8353FSRTAR
U8: SN65HVD35DR; D14
VN: PAD16AWG_TERM; 16AWG_TERM
VP: PAD16AWG_TERM; 16AWG_TERM
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

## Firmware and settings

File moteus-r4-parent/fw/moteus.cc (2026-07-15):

// Copyright 2023 mjbots Robotic Systems, LLC.  info@mjbots.com
//
// Licensed under the Apache License, Version 2.0 (the "License");
// you may not use this file except in compliance with the License.
// You may obtain a copy of the License at
//
//     http://www.apache.org/licenses/LICENSE-2.0
//
// Unless required by applicable law or agreed to in writing, software
// distributed under the License is distributed on an "AS IS" BASIS,
// WITHOUT WARRANTIES OR CONDITIONS OF ANY KIND, either express or implied.
// See the License for the specific language governing permissions and
// limitations under the License.

#include <inttypes.h>

#include <functional>

#include "mbed.h"

#include "mjlib/micro/async_exclusive.h"
#include "mjlib/micro/async_stream.h"
#include "mjlib/micro/command_manager.h"
#include "mjlib/micro/persistent_config.h"
#include "mjlib/micro/telemetry_manager.h"
#include "mjlib/multiplex/micro_server.h"
#include "mjlib/multiplex/micro_stream_datagram.h"

#include "fw/board_debug.h"
#include "fw/clock_manager.h"
#include "fw/firmware_info.h"
#include "fw/git_info.h"
#include "fw/millisecond_timer.h"
#include "fw/moteus_controller.h"
#include "fw/moteus_hw.h"
#include "fw/system_info.h"
#include "fw/uuid.h"

#if defined(TARGET_STM32G4)
#include "fw/fdcan.h"
#include "fw/fdcan_micro_server.h"
#include "fw/multi_transport_datagram_server.h"
#include "fw/stm32g4_flash.h"
#else
#error "Unknown target"
#endif

extern "C" {
  uint32_t kMoteusFirmwareVersion = MOTEUS_FIRMWARE_VERSION;
}

auto* const MyDWT = DWT;
auto* const MyFLASH = FLASH;

using namespace moteus;
namespace micro = mjlib::micro;
namespace multiplex = mjlib::multiplex;

#if defined(TARGET_STM32G4)
using Stm32Flash = Stm32G4Flash;
#else
#error "Unknown target"
#endif

extern "C" {
void SetupClock() {
#if defined(TARGET_STM32G4)
  {
    __HAL_RCC_SYSCFG_CLK_ENABLE();
    __HAL_RCC_PWR_CLK_ENABLE();

    RCC_ClkInitTypeDef RCC_ClkInitStruct;

    RCC_ClkInitStruct.ClockType      = (RCC_CLOCKTYPE_SYSCLK | RCC_CLOCKTYPE_HCLK | RCC_CLOCKTYPE_PCLK1 | RCC_CLOCKTYPE_PCLK2);
    RCC_ClkInitStruct.SYSCLKSource = RCC_SYSCLKSOURCE_PLLCLK;
    RCC_ClkInitStruct.AHBCLKDivider = RCC_SYSCLK_DIV1; // 170 MHz
    RCC_ClkInitStruct.APB1CLKDivider = RCC_HCLK_DIV2;  //  85 MHz
    RCC_ClkInitStruct.APB2CLKDivider = RCC_HCLK_DIV2;  //  85 MHz

    if (HAL_RCC_ClockConfig(&RCC_ClkInitStruct, FLASH_LATENCY_6) != HAL_OK) {
      mbed_die();
    }

    RCC_PeriphCLKInitTypeDef PeriphClkInit = {};

    PeriphClkInit.PeriphClockSelection =
        RCC_PERIPHCLK_FDCAN |
        RCC_PERIPHCLK_USART1 |
        RCC_PERIPHCLK_USART2 |
        RCC_PERIPHCLK_USART3 |
        RCC_PERIPHCLK_ADC12 |
        RCC_PERIPHCLK_ADC345 |
        RCC_PERIPHCLK_I2C1 |
        RCC_PERIPHCLK_I2C2
        ;
    PeriphClkInit.FdcanClockSelection = RCC_FDCANCLKSOURCE_PCLK1;
    // Each USART instance uses its natural APB clock (PCLK2 for
    // USART1, PCLK1 for USART2/USART3); mbed's serial_baud queries
    // the matching PCLK frequency for baud-rate computation.
    PeriphClkInit.Usart1ClockSelection = RCC_USART1CLKSOURCE_PCLK2;
    PeriphClkInit.Usart2ClockSelection = RCC_USART2CLKSOURCE_PCLK1;
    PeriphClkInit.Usart3ClockSelection = RCC_USART3CLKSOURCE_PCLK1;
    PeriphClkInit.Adc12ClockSelection = RCC_ADC12CLKSOURCE_SYSCLK;
    PeriphClkInit.Adc345ClockSelection = RCC_ADC345CLKSOURCE_SYSCLK;
    // Both I2C peripherals run from SYSCLK so Stm32I2c can use a
    // single HAL_RCC_GetSysClockFreq() reading for the timing
    // calculator regardless of which instance any given aux port
    // happens to route to.
    PeriphClkInit.I2c1ClockSelection = RCC_I2C1CLKSOURCE_SYSCLK;
    PeriphClkInit.I2c2ClockSelection = RCC_I2C2CLKSOURCE_SYSCLK;
    if (HAL_RCCEx_PeriphCLKConfig(&PeriphClkInit) != HAL_OK) {
      mbed_die();
    }

    __HAL_RCC_TIM1_CLK_ENABLE();
    __HAL_RCC_TIM2_CLK_ENABLE();
    __HAL_RCC_TIM3_CLK_ENABLE();
    __HAL_RCC_TIM4_CLK_ENABLE();
  }
#endif
}
}

#if defined(TARGET_STM32G4)
extern "C" {
extern char _sccmram;
extern char _siccmram;
extern char _eccmram;
extern char _sccmram;
}
#endif

namespace moteus {
volatile uint8_t g_measured_hw_family;
volatile uint8_t g_measured_hw_rev;
volatile uint8_t g_measured_hw_pins;
MoteusHwPins g_hw_pins;
}

namespace {
struct CanConfig {
  uint32_t prefix = 0;

  template <typename Archive>
  void Serialize(Archive* a) {
    a->Visit(MJ_NVP(prefix));
  }

  bool operator==(const CanConfig& rhs) const {
    return prefix == rhs.prefix;
  }
};
}

int main(void) {
#if defined(TARGET_STM32G4)
  std::memcpy(&_sccmram, &_siccmram, &_eccmram - &_sccmram);
#endif

  FLASH->ACR |= FLASH_ACR_PRFTEN | FLASH_ACR_ICEN | FLASH_ACR_DCEN;

#if 0
  // We map SRAM1 onto address 0 just to make finding accesses to
  // address 0 easier.
  SYSCFG->MEMRMP = (SYSCFG->MEMRMP & ~SYSCFG_MEMRMP_MEM_MODE_Msk) | 0x03;  // SRAM1
#endif

  SetupClock();

  // I initially used a Ticker here to enqueue events at 1ms
  // intervals.  However, it introduced jitter into the current
  // sampling interrupt, and I couldn't figure out how to get the
  // interrupt priorities right.  Thus for now we just poll to look
  // for millisecond turnover.
  MillisecondTimer timer;

  const auto family_and_version = DetectMoteusFamily(&timer);
  g_measured_hw_family = family_and_version.family;
  g_measured_hw_rev = family_and_version.hw_version;
  g_measured_hw_pins = family_and_version.hw_pins;

  g_hw_pins = FindHardwarePins(family_and_version);

  // We do our compatibility check *after* calling FindHardwarePins so
  // the the family specific pins are known.  That way mbed_die
  // doesn't choke being unable to find the power LED for instance.

  if (family_and_version.hw_version < 0) {
    // This firmware is not compatible with this board.
    mbed_die();
  }

  // We require cycle counting be enabled for some things.
  {
    ITM->LAR = 0xC5ACCE55;
    CoreDebug->DEMCR |= CoreDebug_DEMCR_TRCENA_Msk;
    DWT->CYCCNT = 0;
    DWT->CTRL |= DWT_CTRL_CYCCNTENA_Msk;
  }

  // Turn on our power light.
  DigitalOut power_led(g_hw_pins.power_led, 0);

  micro::SizedPool<24000> pool;

  FDCan fdcan([]() {
      FDCan::Options options;

      options.td = g_hw_pins.can_td;
      options.rd = g_hw_pins.can_rd;

      options.slow_bitrate = 1000000;
      options.fast_bitrate = 5000000;

      options.fdcan_frame = true;
      options.bitrate_switch = true;
      options.automatic_retransmission = true;

      // Family 0 uses a TCAN334GDCNT, which has a very low loop
      // delay.  Other families use chips with a longer loop delay.
      options.delay_compensation = g_measured_hw_family != 0;

      options.tdc_offset = 13;  // 13 / 85MHz ~= 152ns
      options.tdc_filter = 2; // 2 / 85MHz ~= 23ns

      return options;
    }());
  FDCanMicroServer fdcan_micro_server(&fdcan);

  MultiTransportDatagramServer multi_transport(&fdcan_micro_server);

  multiplex::MicroServer multiplex_protocol(
      &pool, &multi_transport,
      []() {
        multiplex::MicroServer::Options options;
        options.max_tunnel_streams = 3;
        return options;
      }());

  micro::AsyncStream* serial = multiplex_protocol.MakeTunnel(1);

  micro::AsyncExclusive<micro::AsyncWriteStream> write_stream(serial);
  micro::CommandManager command_manager(&pool, serial, &write_stream);
  char micro_output_buffer[2048] = {};
  micro::TelemetryManager telemetry_manager(
      &pool, &command_manager, &write_stream, micro_output_buffer);
  Stm32Flash flash_interface;
  micro::PersistentConfig persistent_config(
      pool, command_manager, flash_interface, micro_output_buffer);

  SystemInfo system_info(pool, telemetry_manager);
  FirmwareInfo firmware_info(pool, telemetry_manager,
                             kMoteusFirmwareVersion, MOTEUS_MODEL_NUMBER);
  Uuid uuid(persistent_config);
  ClockManager clock(&timer, persistent_config, command_manager);

  MoteusController moteus_controller(
      &pool, &persistent_config,
      &command_manager,
      &telemetry_manager,
      &multiplex_protocol,
      &multi_transport,
      &clock,
      &system_info,
      &timer,
      &firmware_info,
      &uuid);

  BoardDebug board_debug(
      &pool, &command_manager, &telemetry_manager, &multiplex_protocol,
      moteus_controller.bldc_servo());

  GitInfo git_info;
  telemetry_manager.Register("git", &git_info);

  CanConfig can_config, old_can_config;

  // We always want to update our filters at least once.
  uint8_t old_multiplex_id = 255;

  const auto maybe_update_filters =
      [&can_config, &fdcan, &multi_transport, &old_can_config,
       &old_multiplex_id, &multiplex_protocol]() {
        // Prevent the ID from being set to an unusable value.
        if (multiplex_protocol.config()->id < 1 ||
            multiplex_protocol.config()->id > 126) {
          multiplex_protocol.config()->id = 1;
        }

        // We only update our config if it has actually changed.
        // Re-initializing the CAN-FD controller can cause packets to
        // be lost, so don't do it unless actually necessary.
        if (can_config == old_can_config &&
            multiplex_protocol.config()->id == old_multiplex_id) {
          return;
        }
        old_can_config = can_config;
        old_multiplex_id = multiplex_protocol.config()->id;

        FDCan::Filter filters[4] = {};
        filters[0].id1 = (can_config.prefix << 16) | old_multiplex_id;
        filters[0].id2 = 0x1fff00ffu;
        filters[0].mode = FDCan::FilterMode::kMask;
        filters[0].action = FDCan::FilterAction::kAccept;
        filters[0].type = FDCan::FilterType::kExtended;

        filters[1].id1 = (can_config.prefix << 16) | 0x7f;
        filters[1].id2 = 0x1fff00ffu;
        filters[1].mode = FDCan::FilterMode::kMask;
        filters[1].action = FDCan::FilterAction::kAccept;
        filters[1].type = FDCan::FilterType::kExtended;

        filters[2].id1 = (can_config.prefix << 16) | old_multiplex_id;
        filters[2].id2 = 0x1fff00ffu;
        filters[2].mode = FDCan::FilterMode::kMask;
        filters[2].action = FDCan::FilterAction::kAccept;
        filters[2].type = FDCan::FilterType::kStandard;

        filters[3].id1 = (can_config.prefix << 16) | 0x7f;
        filters[3].id2 = 0x1fff00ffu;
        filters[3].mode = FDCan::FilterMode::kMask;
        filters[3].action = FDCan::FilterAction::kAccept;
        filters[3].type = FDCan::FilterType::kStandard;

        FDCan::FilterConfig filter_config;
        filter_config.begin = std::begin(filters);
        filter_config.end = std::end(filters);
        filter_config.global_std_action = FDCan::FilterAction::kReject;
        filter_config.global_ext_action = FDCan::FilterAction::kReject;
        fdcan.ConfigureFilters(filter_config);

        // Set prefix on both CAN-FD and UART transports
        multi_transport.SetPrefix(can_config.prefix);
      };

  persistent_config.Register("id", multiplex_protocol.config(), maybe_update_filters);

  persistent_config.Register("can", &can_config, maybe_update_filters);

  persistent_config.Load();

  moteus_controller.Start();
  command_manager.AsyncStart();
  multiplex_protocol.Start(moteus_controller.multiplex_server());

  auto old_time = timer.read_us();

  for (;;) {
#if defined(TARGET_STM32G4)
    multi_transport.Poll();
#endif
    moteus_controller.Poll();
    multiplex_protocol.Poll();

    const auto new_time = timer.read_us();

    const auto delta_us = MillisecondTimer::subtract_us(new_time, old_time);
    if (moteus_controller.bldc_servo()->config().timing_fault &&
        delta_us >= 4000) {
      // We missed several entire polling cycles.  Fault if we can.
      moteus_controller.bldc_servo()->Fault(moteus::errc::kTimingViolation);
    }

    if (delta_us >= 1000) {
      telemetry_manager.PollMillisecond();
      system_info.PollMillisecond();
      moteus_controller.PollMillisecond();
      board_debug.PollMillisecond();
      system_info.SetCanResetCount(multi_transport.can_reset_count());
      timer.AdvanceMsSinceBoot();

      old_time += 1000;
    }

    SystemInfo::idle_count++;
  }

  return 0;
}

extern "C" {
  void abort() {
    mbed_die();
  }
}

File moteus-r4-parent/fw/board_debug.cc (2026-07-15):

// Copyright 2023 mjbots Robotic Systems, LLC.  info@mjbots.com
//
// Licensed under the Apache License, Version 2.0 (the "License");
// you may not use this file except in compliance with the License.
// You may obtain a copy of the License at
//
//     http://www.apache.org/licenses/LICENSE-2.0
//
// Unless required by applicable law or agreed to in writing, software
// distributed under the License is distributed on an "AS IS" BASIS,
// WITHOUT WARRANTIES OR CONDITIONS OF ANY KIND, either express or implied.
// See the License for the specific language governing permissions and
// limitations under the License.

#include "fw/board_debug.h"

#include <cctype>
#include <cstdlib>
#include <functional>
#include <numeric>

#include "mbed.h"

#include "mjlib/base/inplace_function.h"
#include "mjlib/base/tokenizer.h"
#include "mjlib/base/visitor.h"

#include "fw/as5047.h"
#include "fw/bldc_servo.h"
#include "fw/bootloader.h"
#include "fw/drv8323.h"
#include "fw/moteus_hw.h"
#include "fw/strtof.h"

namespace base = mjlib::base;
namespace micro = mjlib::micro;
namespace multiplex = mjlib::multiplex;

namespace moteus {
constexpr float kCalibrationStep = 0.002;
constexpr float kMaxCalPoleCount = 50.0f;

namespace {
void recurse(int count, base::inplace_function<void(int)> callback) {
  callback(count - 1);
}

bool ParseOptions(BldcServo::CommandData* command, base::Tokenizer* tokenizer,
                  const char* valid_options) {
  while (tokenizer->remaining().size()) {
    const auto token = tokenizer->next();
    // We accept optional arguments, each prefixed by a single
    // character.
    if (token.size() < 1) { continue; }
    const char option = token[0];
    if (::strchr(valid_options, option) == nullptr) {
      return false;
    }

    const auto maybe_value = Strtof(&token[1]);
    if (!maybe_value) {
      return false;
    }
    const auto value = *maybe_value;
    switch (option) {
      case 'p': {
        command->kp_scale = value;
        break;
      }
      case 'd': {
        command->kd_scale = value;
        break;
      }
      case 'i': {
        command->ilimit_scale = value;
        break;
      }
      case 's': {
        command->stop_position = value;
        break;
      }
      case 'f': {
        command->feedforward_Nm = value;
        break;
      }
      case 't': {
        command->timeout_s = value;
        break;
      }
      case 'a': {
        command->accel_limit = value;
        break;
      }
      case 'v': {
        command->velocity_limit = value;
        break;
      }
      case 'o': {
        command->fixed_voltage_override = value;
        break;
      }
      case 'c': {
        command->fixed_current_override = value;
        break;
      }
      case 'b': {
        command->ignore_position_bounds = value != 0.0f;
        break;
      }
      case 'q': {
        command->meas_ind_axis = static_cast<int8_t>(value);
        break;
      }
      default: {
        return false;
      }
    }
  }
  return true;
}
}

class BoardDebug::Impl {
 public:
  struct HistogramSource;

  Impl(micro::Pool* pool,
       micro::CommandManager* command_manager,
       micro::TelemetryManager* telemetry_manager,
       multiplex::MicroServer* multiplex_protocol,
       BldcServo* bldc_servo)
      : multiplex_protocol_(multiplex_protocol),
        bldc_(bldc_servo) {
    command_manager->Register(
        "d", std::bind(&Impl::HandleCommand, this,
                       std::placeholders::_1, std::placeholders::_2));

    data_update_ = telemetry_manager->Register("board_debug", &data_);
  }

  void PollMillisecond() {
    if (motor_cal_mode_ != kNoMotorCal) {
      DoCalibration();
    }
    if (histogram_active_) {
      DoHistogram();
    }
  }

  bool ParseHistogramChannel(HistogramSource* source, const std::string_view& spec) {
    // The format of this specification is a single character source:
    //
    //  t - electrical theta
    //  c - compensated
    //  f - filtered
    //  o - offset
    //  r - raw
    //  v - pll output velocity
    //  ... etc ...
    //
    // followed by an optional single digit to specify the encoder
    // channel, and then an optional list of non-digit flags:
    //
    //  d - derivative

    source->derivative = false;
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

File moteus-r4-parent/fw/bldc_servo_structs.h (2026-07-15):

// Copyright 2023 mjbots Robotic Systems, LLC.  info@mjbots.com
//
// Licensed under the Apache License, Version 2.0 (the "License");
// you may not use this file except in compliance with the License.
// You may obtain a copy of the License at
//
//     http://www.apache.org/licenses/LICENSE-2.0
//
// Unless required by applicable law or agreed to in writing, software
// distributed under the License is distributed on an "AS IS" BASIS,
// WITHOUT WARRANTIES OR CONDITIONS OF ANY KIND, either express or implied.
// See the License for the specific language governing permissions and
// limitations under the License.

#pragma once

#include <cstdint>
#include <optional>

#include "mjlib/base/visitor.h"

#include "fw/error.h"
#include "fw/measured_hw_rev.h"
#include "fw/pid.h"
#include "fw/simple_pi.h"

namespace moteus {

struct Vec3 {
  float a = 0.0f;
  float b = 0.0f;
  float c = 0.0f;

  template <typename Archive>
  void Serialize(Archive* ar) {
    ar->Visit(MJ_NVP(a));
    ar->Visit(MJ_NVP(b));
    ar->Visit(MJ_NVP(c));
  }
};

struct FieldWeakeningConfig {
  bool enable = false;
  float modulation_margin = 0.15f;

  // The cutoff frequency for the low-pass filter on the FW Id
  // command.  This limits how fast the field weakening current can
  // change.
  float bandwidth_hz = 100.0f;

  float max_current_ratio = 0.5f;

  template <typename Archive>
  void Serialize(Archive* a) {
    a->Visit(MJ_NVP(enable));
    a->Visit(MJ_NVP(modulation_margin));
    a->Visit(MJ_NVP(bandwidth_hz));
    a->Visit(MJ_NVP(max_current_ratio));
  }
};

struct FieldWeakeningStatus {
  float id_A = 0.0f;
  // Characteristic current psi_m / L_d, computed per-cycle from the
  // dynamic D-axis inductance.
  float id_char = 0.0f;

  template <typename Archive>
  void Serialize(Archive* a) {
    a->Visit(MJ_NVP(id_A));
    a->Visit(MJ_NVP(id_char));
  }
};

enum BldcServoMode {
  // In this mode, the entire motor driver will be disabled.
  //
  // When exiting this state, the current offset will be
  // recalibrated.
  kStopped = 0,

  // This stage cannot be commanded directly, but will be entered
  // upon any fault.  Here, the motor driver remains enabled, but
  // the output stage power is removed.  The only valid transition
  // from this state is to kStopped.
  kFault = 1,

  // This mode may not be commanded directly.  It is used when
  // transitioning from kStopped to another mode.
  kEnabling = 2,

  // This mode may not be commanded directly, but is used when
  // transitioning from kStopped to another mode.
  kCalibrating = 3,

  // This mode may not be commanded directly, but is used when
  // transitioning from kStopped to another mode.
  kCalibrationComplete = 4,

  // Directly control the PWM of all 3 phases.
  kPwm = 5,

  // Control the voltage of all three phases
  kVoltage = 6,

  // Control the phase and voltage magnitude
  kVoltageFoc = 7,

  // Control d and q voltage
  kVoltageDq = 8,

  // Control d and q current
  kCurrent = 9,

  // Control absolute position
  kPosition = 10,

  // This state can be commanded directly, and will also be entered
  // automatically upon a watchdog timeout from kPosition.  When in
  // this state, the controller will apply the selected fallback
  // control mode.
  //
  // The only way to exit this state is through a stop command.
  kPositionTimeout = 11,

  // Control to zero velocity through a derivative only version of
  // the position mode.
  kZeroVelocity = 12,

  // This applies the PID controller only to stay within a
  // particular position region, and applies 0 torque when within
  // that region.
  kStayWithinBounds = 13,

  // This mode applies a fixed voltage square waveform to measure
  // inductance.  The meas_ind_axis field selects whether the D or Q
  // axis is excited.
  kMeasureInductance = 14,

  // All phases are pulled to ground.
  kBrake = 15,

  kNumModes,
};

struct BldcServoStatus {
  BldcServoMode mode = kStopped;
  errc fault = errc::kSuccess;

  uint16_t adc_cur1_raw = 0;
  uint16_t adc_cur2_raw = 0;
  uint16_t adc_cur3_raw = 0;
  uint16_t adc_voltage_sense_raw = 0;
  uint16_t adc_fet_temp_raw = 0;
  uint16_t adc_motor_temp_raw = 0;

  uint16_t adc_cur1_offset = 2048;
  uint16_t adc_cur2_offset = 2048;
  uint16_t adc_cur3_offset = 2048;

  float cur1_A = 0.0f;
  float cur2_A = 0.0f;
  float cur3_A = 0.0f;

  float electrical_theta = 0.0f;

  float bus_V = 0.0f;
  float filt_bus_V = std::numeric_limits<float>::quiet_NaN();
  float filt_1ms_bus_V = std::numeric_limits<float>::quiet_NaN();
  float fet_temp_C = 0.0f;
  float filt_fet_temp_C = std::numeric_limits<float>::quiet_NaN();
  float motor_temp_C = 0.0f;
  float filt_motor_temp_C = std::numeric_limits<float>::quiet_NaN();

  float inductance_d_H = 0.0f;

  float d_A = 0.0f;
  float q_A = 0.0f;

  float position = 0.0f;
  float velocity = 0.0f;
  float torque_Nm = 0.0f;
  float power_W = 0.0f;

  float velocity_filt = 0.0f;

  SimplePI::State pid_d;
  SimplePI::State pid_q;
  PID::State pid_position;

  // This is measured in the same units as MotorPosition's integral
  // units, which is 48 bits to represent 1.0 unit of output
  // revolution.
  std::optional<int64_t> control_position_raw;
  float control_position = std::numeric_limits<float>::quiet_NaN();
  std::optional<float> control_velocity;
  float control_acceleration = 0.0f;
  float timeout_s = 0.0;
  bool trajectory_done = false;

  float motor_max_velocity = 0.0f;
  float motor_base_velocity = 0.0f;
  float max_power_W = 0.0f;
  float effective_max_current_A = 0.0f;

  FieldWeakeningStatus fw;

  float torque_error_Nm = 0.0f;

  float sin = 0.0f;
  float cos = 0.0f;
  uint16_t cooldown_count = 0;
  uint32_t final_timer = 0;
  uint32_t total_timer = 0;

  float meas_ind_old_d_A = 0.0f;
  float meas_ind_old_q_A = 0.0f;
  int8_t meas_ind_phase = 0;
  float meas_ind_integrator = 0.0f;
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

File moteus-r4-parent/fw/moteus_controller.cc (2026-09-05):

// Copyright 2023 mjbots Robotic Systems, LLC.  info@mjbots.com
//
// Licensed under the Apache License, Version 2.0 (the "License");
// you may not use this file except in compliance with the License.
// You may obtain a copy of the License at
//
//     http://www.apache.org/licenses/LICENSE-2.0
//
// Unless required by applicable law or agreed to in writing, software
// distributed under the License is distributed on an "AS IS" BASIS,
// WITHOUT WARRANTIES OR CONDITIONS OF ANY KIND, either express or implied.
// See the License for the specific language governing permissions and
// limitations under the License.

#include "fw/moteus_controller.h"

#include "mjlib/base/limit.h"

#include "fw/aux_port.h"
#include "fw/drv8323.h"
#include "fw/math.h"
#include "fw/moteus_hw.h"
#include "fw/motor_position.h"
#include "fw/multi_transport_datagram_server.h"
#include "fw/uart_fdcanusb_micro_server.h"
#include "fw/ws2812_led.h"

namespace micro = mjlib::micro;
namespace multiplex = mjlib::multiplex;
using mjlib::base::Limit;

namespace moteus {

using Value = multiplex::MicroServer::Value;

namespace {

// Version 3: The enumerated values for the control mode changed
// meaning and voltage scale changed.
//
// Version 4: The scaling factors associated with velocity and
// position changed.
//
// Version 5: The "rezero state" was renamed to "home state" and the
// enumeration has new meaning.

constexpr int kRegisterMapVersion = 5;

// FlexNode block (0x080-0x0ff) layout version; bump on any layout change.
constexpr int kFlexNodeBlockVersion = 1;
// Capability bits for reg 0x080.
constexpr int kFlexCapImu = 1 << 2;
constexpr int kFlexCapPixel = 1 << 4;

// LSM6DS3TR-C scaling at the fixed full-scales configured in aux_port.h.
constexpr float kImuAccelGPerLsb = 0.000122f;   // +/-4 g
constexpr float kImuGyroDpsPerLsb = 0.0175f;    // +/-500 dps

template <typename T>
Value IntMapping(T value, size_t type) {
  switch (type) {
    case 0: return static_cast<int8_t>(value);
    case 1: return static_cast<int16_t>(value);
    case 2: return static_cast<int32_t>(value);
    case 3: return static_cast<float>(value);
  }
  MJ_ASSERT(false);
  return static_cast<int8_t>(0);
}

template <typename T>
Value ScaleSaturate(float value, float scale) {
  if (!std::isfinite(value)) {
    return std::numeric_limits<T>::min();
  }

  const float scaled = value / scale;
  const auto max = std::numeric_limits<T>::max();
  const auto float_max = static_cast<float>(max);

  // We purposefully limit to +- max, rather than to min.  The minimum
  // value for our two's complement types is reserved for NaN.
  return static_cast<T>(Limit<float>(scaled, -float_max, float_max));
}

Value ScaleMapping(float value,
                   float int8_scale, float int16_scale, float int32_scale,
                   size_t type) {
  switch (type) {
    case 0: return ScaleSaturate<int8_t>(value, int8_scale);
    case 1: return ScaleSaturate<int16_t>(value, int16_scale);
    case 2: return ScaleSaturate<int32_t>(value, int32_scale);
    case 3: return Value(value);
  }
  MJ_ASSERT(false);
  return Value(static_cast<int8_t>(0));
}

Value ScalePosition(float value, size_t type) {
  return ScaleMapping(value, 0.01f, 0.0001f, 0.00001f, type);
}

Value ScaleVelocity(float value, size_t type) {
  return ScaleMapping(value, 0.1f, 0.00025f, 0.00001f, type);
}

Value ScaleAcceleration(float value, size_t type) {
  return ScaleMapping(value, 0.05f, 0.001f, 0.00001f, type);
}

Value ScaleTemperature(float value, size_t type) {
  return ScaleMapping(value, 1.0f, 0.1f, 0.001f, type);
}

Value ScalePwm(float value, size_t type) {
  return ScaleMapping(value, 1.0f / 127.0f, 1.0f / 32767.0f,
                      1.0f / 2147483647.0f,
                      type);
}

Value ScaleCurrent(float value, size_t type) {
  // For now, current and temperature have identical scaling.
  return ScaleTemperature(value, type);
}

Value ScaleVoltage(float value, size_t type) {
  return ScaleMapping(value, 0.5f, 0.1f, 0.001f, type);
}

Value ScaleTorque(float value, size_t type) {
  return ScaleMapping(value, 0.5f, 0.01f, 0.001f, type);
}

Value ScaleTime(float value, size_t type) {
  return ScaleMapping(value, 0.01f, 0.001f, 0.000001f, type);
}

Value ScalePower(float value, size_t type) {
  return ScaleMapping(value, 10.0f, 0.05f, 0.0001f, type);
}

int8_t ReadIntMapping(Value value) {
  return std::visit([](auto a) {
    return static_cast<int8_t>(a);
  }, value);
}

int32_t ReadInt32Mapping(Value value) {
  return std::visit([](auto a) {
    return static_cast<int32_t>(a);
  }, value);
}

struct ValueScaler {
  float int8_scale;
  float int16_scale;
  float int32_scale;

  float operator()(int8_t value) const {
    if (value == std::numeric_limits<int8_t>::min()) {
      return std::numeric_limits<float>::quiet_NaN();
    }
    return value * int8_scale;
  }

  float operator()(int16_t value) const {
    if (value == std::numeric_limits<int16_t>::min()) {
      return std::numeric_limits<float>::quiet_NaN();
    }
    return value * int16_scale;
  }

  float operator()(int32_t value) const {
    if (value == std::numeric_limits<int32_t>::min()) {
      return std::numeric_limits<float>::quiet_NaN();
    }
    return value * int32_scale;
  }

  float operator()(float value) const {
    return value;
  }
};

float ReadScaleMapping(Value value,
                       float int8_scale,
                       float int16_scale,
                       float int32_scale) {
  return std::visit(ValueScaler{int8_scale, int16_scale, int32_scale}, value);
}

float ReadPwm(Value value) {
  return ReadScaleMapping(value, 1.0f / 127.0f, 1.0f / 32767.0f,
                          1.0f / 2147483647.0f);
}

float ReadVoltage(Value value) {
  return ReadScaleMapping(value, 0.5f, 0.1f, 0.001f);
}

float ReadPosition(Value value) {
  return ReadScaleMapping(value, 0.01f, 0.0001f, 0.00001f);
}

float ReadVelocity(Value value) {
  return ReadScaleMapping(value, 0.1f, 0.00025f, 0.00001f);
}

float ReadAcceleration(Value value) {
  return ReadScaleMapping(value, 0.05f, 0.001f, 0.00001f);
}

float ReadCurrent(Value value) {
  return ReadScaleMapping(value, 1.0f, 0.1f, 0.001f);
}

float ReadTorque(Value value) {
  return ReadScaleMapping(value, 0.5f, 0.01f, 0.001f);
}

float ReadTime(Value value) {
  return ReadScaleMapping(value, 0.01f, 0.001f, 0.000001f);
}

template <typename T, size_t N>
int8_t PinsToBits(const std::array<T, N>& array) {
  static_assert(N <= 7);
  int8_t result = 0;
  for (size_t i = 0; i < array.size(); i++) {
    result |= (array[i] ? 1 : 0) << i;
  }
  return result;
}
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

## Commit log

2026-07-15 @ Add FlexNode: distributed CAN-FD compute node (hardware + docs)
    FlexNode is a mobile-robot node built on this moteus r4.11 fork: high-
    current FOC actuation + sensor fusion (IMU, ToF) over CAN-FD, for the
    CATBOT quadruped. This commit adds the FlexNode v1.0 hardware artifacts
    and documentation under flexnode/; the firmware port (moteus deltas)
    follows in fw/.
    flexnode/
    README.md, docs/ (hardware, firmware port plan, roadmap)
    hardware/ (v1.0 schematic, BOM, gerbers, pick-and-place, 3D STEP)
    Documents the key firmware deltas vs stock moteus: hw_version=8
    hardcode, pin remaps (PB11->5V sense, PC6->AS5047 CS, PC13->servo/LED),
    and the phase-order fix (swap current-sense phase-0<->2 to ma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
    [FNv1.0bom_YES.xlsx, FlexNode.step, Pick Place for FlexNodePCB.csv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]
2026-07-15 @ Restructure: FlexNode at root, moteus relocated to moteus-r4-parent/
    Make FlexNode the top-level project so the repo opens on FlexNode's
    README instead of moteus's. Moved the entire moteus r4.11 tree into
    moteus-r4-parent/ (tracked as renames — full moteus history preserved)
    and promoted FlexNode's README/docs/hardware to the root.
    - Root: README.md, docs/, hardware/, LICENSE (Apache-2.0), .gitignore
    - moteus-r4-parent/: moteus firmware + build system + ABOUT-THIS-FOLDER.md
    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
    [20200729-moteus-controller-r43-mechanical.step, 20210124-moteus-controller-r45-mechanical.step, 20230226-moteus-n1-mechanical.step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]
2026-07-21 fw: FlexNode board identity + pin compat layer (r4.11-class, DRV8353S path, drive-side phase re-pair)
2026-07-24 fw: encode as-built R30 (1.2k) bus-voltage divider in vsense scale; docs: rescale rationale + 8S bring-up config
2026-09-05 fw: WS2812B status/lighting driver on PF0; first boot + first light on v1.0 hardware
    First article booted 2026-09-06: SWD probe, nSWBOOT0 option byte, bare-metal
    LED test, then this image - steady soft blue on the onboard pixel.
    - fw/ws2812_led.{h,cc}: addressable-LED chain on one GPIO. Pixel 0 is the
    node's own status LED, pixels 1..led.count are master-control lighting.
    All pixels show led.master_r/g/b at led.brightness unless individually
    set via SetPixel() (hook for the CAN register block). While the servo is
    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
2026-09-05 docs: first article booted 2026-09-06 - validated vs pending
    A v1.0 board powered from a 13 V bench adapter now boots from flash and
    runs the FlexNode firmware: 5 V / 3.3 V rails stable, SWD flash path
    working (ST-Link V2), WS2812B status LED on PF0 live, servo in stopped
    mode. No motor and no encoder are fitted; the gate driver has never been
    energized.
    - firmware.md: replace the pre-bring-up note with what is validated vs
    pending; mark checklist items 1 and 4 done, 2 partial (CAN enumeration
    and telemetry still outstanding); update the measured image size to
    429,208 B (~25 KiB free).
    - roadmap.md: assembly and power-on smoke test done; nSWBOOT0 and the
    WS2812 driver marked complet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
2026-09-05 fw: LSM6DS3TR-C IMU as aux2 I2C device (on by default) + FlexNode register block skeleton
    IMU
    - aux_common.h: new I2C device type kLsm6ds3 and a kBoardDefault type that
    AuxPort resolves to the board's onboard I2C device (else kNone); new
    aux::I2C::ImuStatus (active, whoami, raw ax/ay/az gx/gy/gz temp, nonce,
    error_count) exported under aux2.i2c.imu.
    - aux_port.h: I2cDefault ctor option; kDefaultOnboardLsm6ds3 makes
    aux2.i2c.devices.0 the IMU at 0x6A / 10 ms and claims the I2C pins.
    Init = one burst write CTRL1_XL/CTRL2_G/CTRL3_C (104 Hz, +/-4 g,
    +/-500 dps, BDU+IF_INC), WHO_AM_I check, then 14-byte OUT_TEMP_L bursts.
    - moteus_controller.cc: aux2 on FlexNode = I2C sensor bus, so i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
    [aux_common.h, aux_port.h, moteus.cc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]
2026-09-06 fw: status LED breathes once on OK, exact DWT bit timing, no periodic refresh
    Pixel 0 (the node's status LED) now gives one blue fade-in (0.9 s) /
    fade-out (1.6 s) on entering the OK state, then stays dark; re-armed each
    time the board returns to OK. Fault blink and led.imu_demo keep precedence.
    External pixels 1..N still hold the master colour.
    Bit timing is measured on the DWT cycle counter with a bounded spin. Two
    open-loop alternatives were tried on hardware and both failed:
    - counted subs/bne loop: ran fast, '0' pulse ~230 ns, below the WS2812B
    detection floor; an all-'0' OFF frame registered nothing so the LED held
    its last colour indefinitely (coloured frames still rendered).
    - u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
    [ws2812_led.cc, ws2812_led.h]
2026-09-06 notes: in-repo build notes + versioned bench tooling
    notes/: practitioner notes so each new session starts from what the last
    one learned. README (index + conventions), working-together (git identity,
    motor-safety gates, the ! prefix for hardware commands, subagent use),
    bench-setup (SWD header, the NRST rule, power, ST-Link driver), build-and-
    flash (WSL build, image layout, flash script modes, option bytes, flash
    budget), debugging-over-swd (PC sampling, reading RAM by symbol, what each
    openocd error meant, reasoning traps), ws2812-led (behaviour + why timing is
    DWT-only), firmware-map (where FlexNode changes live, how to add a register /
    aux I2C device / config group), bringup-log (valida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
    [main.c]
2026-09-06 docs: CAN layer v2 — channel model, profiles, host-loss autonomy
    Rewrites the July design against three changes: FlexNode is a product whose
    register map is a public API, build-time specialisation is now explicitly
    allowed (reflash on hardware change is acceptable), and the fleet must
    survive the Jetson dying.
    Channel model (new, 0x200 + 0x10*slot): a node is one axis plus up to eight
    typed peripheral slots, each with an identical 16-register frame. Because
    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
2026-09-06 docs+notes: measured flash budget, hardware I/O reality, node identity
    Records the session's findings so they survive into future sessions, with
    date+time stamps on each per Aditya's request.
    flash-budget.md / notes/flash-findings.md — measured, and it overturned the
    plan twice. The best lever costs no code: there is a 48,680 B hole in the
    flash map between the 472 B vector table and the bootloader at 0x0800C000,
    which fw/stm32g474.ld itself labels "currently unused". Moving .rodata into
    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
2026-09-06 docs+notes: measured flash variants; correct two hardware claims
    Flash figures replaced with real variant builds rather than estimates.
    newlib-nano measures -33,916 B, the throw-stub TU -12,316 B, and
    moteus_controller.cc at -Os -50,144 B; together -84,028 B, taking the image
    to 353,780 B with 100,876 B free. Plus the 48,680 B unused gap and 19,242 B
    of removable drivers, the ceiling is ~150 kB against 16,848 B free today.
    Two findings worth more than the numbers. Most of the apparent "driver
    bloat" is -O3 inlining, not driver code: under -Os HandleConfigUpdate drops
    13,636 -> 4,788 and AuxStatus::Serialize<BinarySchemaArchive> 4,764 -> 604,
    which is why that lever out-earns deleting driver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
2026-09-06 reports: firmware flash optimisation decision document (2026-09-07)
    Standing report for the owner: the measured -84,028 B from three build-level
    changes (newlib-nano, throw stubs, size-optimised controller TU) removes no
    drivers; what each removable driver is and why MA732, quadrature and the UART
    serial server are worth keeping; decision table with keep-everything as the
    default; the -u _printf_float and link-order caveats; learnings; unmeasured
    items. Adds a reports/ pointer to notes/README.md.
2026-09-06 notes: moteus_tool over serial may unblock the bench without a CAN adapter
    kSerial aux UART mode (aux_common.h:104) speaks the full multiplex register
    protocol over a plain 3.3V UART via UartFdcanusbMicroServer, and family-0
    USART3 is on PB8/PB9 (moteus_controller.cc:462) — the pins broken out on
    FlexNode's J2 I2C header. A USB-TTL adapter may therefore give moteus_tool
    access with no fdcanusb, unblocking node enumeration, the 0x080/0x0FF reads,
    the never-done bus_V-vs-DMM check, a pixel write, and the first exercise of
    the persistent-config page.
    Mutually exclusive with I2C, so the IMU is unavailable while the port is a
    UART — none of the validation list needs it.
    Also flags that kSer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
2026-09-06 reports: CAN layer standing report (2026-09-07)
    Explains and pressure-tests the v2 channel model, cadence and host-loss design for the owner. Recomputes the bus budget with DLC quantisation and extended-id overhead (spec numbers were optimistic; c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
2026-09-06 docs+notes: correct the bus budget; fix stale hardware claims in open-questions
    The bus budget in can-layer §5 was optimistic by 15-20 points. Two effects
    it missed, both verified in source:
    CAN-FD payloads are DLC-quantised (fw/fdcan.cc:24 RoundUpDlc) — there is no
    33-byte frame, so anything from 33 to 48 B costs a full 48 B. And fast-lane
    command frames are 29-bit extended rather than 11-bit, because the host sets
    0x8000 for reply-requested (transport.py:344) and the firmware sends any id
    >= 2048 as extended (fdcan.cc:323); replies from nodes with id >= 8 are
    extended too. That is ~+20 us per frame, paid every frame every cycle.
    Corrected: 13 nodes axis-only at 325 Hz is ~70% not 55%;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
2026-09-07 reports: CATBOT CAN subsystem design (2026-09-08)
    Near-complete design for the 10-node, corenode-master fleet: bitrate vs loop-rate derivation, physical layer (45 cm propagation, chain vs star, termination faults, G4 bit timing, TCAN334G loop delay -> enable TDC), per-class frame layouts with DLC quantisation, round-robin schedule with worked 350 Hz timeline, operating-point table, command/telemetry register mapping, failure policy reworked for a single master (G2 not recommended), and the list of spec changes for docs/can-layer.md. Untested: no CAN adapter on the bench.
2026-09-07 docs+notes: fold the CATBOT CAN subsystem design into the spec
    reports/2026-09-08-can-subsystem-design.md is the near-buildable CATBOT
    instantiation — physical layer, per-node frame layouts, schedule, failure
    policy. This applies its §12 change list to the spec and records the one
    finding that is an action item rather than a design choice.
    Latent bug: TDC is disabled for family 0 (fw/moteus.cc:224) on the grounds
    that the TCAN334G has "very low loop delay". Against the datasheet that is a
    6 ns margin — the firmware's 5 Mbit sample point is 141 ns, worst-case loop
    delay is 135 ns well-terminated and 180 ns heavily loaded, i.e. negative on
    a loaded or single-terminated bus. Two-line fix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
2026-09-07 notes: corenode architecture and the IMU latency finding
    Ahead of corenode schematic capture. Three tiers, each surviving the one
    above: Jetson (allowed to crash), corenode G4 (bus master, basic IK,
    attitude fallback), FlexNode x10 (FOC, on-node loops, G0 timeout).
    Two FDCAN peripherals, not one shared bus. FDCAN1 carries the FlexNode
    chain, FDCAN2 the Jetson link. Putting the Jetson on the fleet bus would
    break the single-master invariant the schedule rests on and let Jetson
    traffic arbitrate against the 350 Hz gait loop. Two peripherals cost two
    transceivers and buy isolation by construction. Wire FDCAN2 even if the
    Jetson link ends up being UART, so the interchangeability stays open.
    Th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
2026-09-08 notes+docs: record the first spin (2026-09-07/08) and the new gates
    bringup-log: add the first-spin entry from the bench/openloop-test commit
    messages (843566b -> 0e29bad): DRV8353S enabled, power stage drove the
    GIM 8108-8 open-loop from the 1.03 A adapter; all three phase-current
    channels calibrate and sum to ~0; stage 2 ran 8 loops / 140 s / zero
    faults with the FETs at 38.7 C; stage 3 sag-aborted cleanly at the
    adapter limit (12.57 -> 10.46 V); bus_V checked against a DMM (12.82 V
    vs 12.50 V) and vsense_adc_scale trimmed on the branch; V-I sweep gives
    phase R and a sensorless winding temperature. Retire the 2026-09-06
    "still gated" table for a 2026-09-08 one; correct the 2026-09-07 entry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
2026-09-08 docs+notes: correct the G0 watchdog scope, flag the AS5047/SPI2 conflict, record first-spin telemetry
    Three corrections from the moteus capability inventory, two of which
    overturn claims in this repo.
    G0 is narrower than can-layer §7 claimed. It called the command watchdog
    "the floor, never disabled". Measured against bldc_servo_control.h:1670-1674,
    the watchdog only fires in mode 10 (position) and mode 13 (stay-within) — a
    node in current, voltage, voltage-FOC, brake or zero-velocity mode has no
    watchdog at all and holds its last command indefinitely if the host stops.
    Recovery is also not automatic: leaving timeout mode needs an explicit stop
    first (:1620-1622), so the design report's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
2026-09-08 README: 21 DoF / 4.9 kg target, first-spin status, moteus-compatible wording; add NOTICE
2026-09-08 Fleet is ten FlexNodes (twelve ordered for attrition); CoreNode is STM32G4; resolve open questions

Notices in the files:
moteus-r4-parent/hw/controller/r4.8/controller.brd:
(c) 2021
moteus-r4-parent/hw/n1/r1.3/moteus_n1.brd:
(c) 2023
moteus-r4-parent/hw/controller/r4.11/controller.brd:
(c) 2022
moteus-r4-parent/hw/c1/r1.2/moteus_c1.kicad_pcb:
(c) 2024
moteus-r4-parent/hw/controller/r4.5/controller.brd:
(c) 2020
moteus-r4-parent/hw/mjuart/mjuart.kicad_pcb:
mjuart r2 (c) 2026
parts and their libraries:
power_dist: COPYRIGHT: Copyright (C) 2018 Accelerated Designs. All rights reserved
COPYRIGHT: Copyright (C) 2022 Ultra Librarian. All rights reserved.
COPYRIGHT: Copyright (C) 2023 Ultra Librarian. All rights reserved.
